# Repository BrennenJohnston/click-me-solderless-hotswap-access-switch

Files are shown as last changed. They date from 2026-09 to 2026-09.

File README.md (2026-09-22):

<!--- Repository structure follows the Open Assistive Technology (OpenAT) Template by Makers Making Change --->

# Click Me: Solderless Hot-Swap Access Switch

A 3D-printed accessibility switch you build without soldering, where the button
itself is an ordinary mechanical keyboard switch you can swap in seconds to change
how hard it is to press.

- **Ordering guide**: `Documentation/ORDERING.md`
- **Assembly guide**: `Documentation/ASSEMBLY.md`
- **Bill of materials**: `Documentation/BOM.csv`
- **Assembly animation**: [youtu.be/RXbbdtwFPiI](https://youtu.be/RXbbdtwFPiI)
- **Status**: work in progress. Built and used, still being iterated

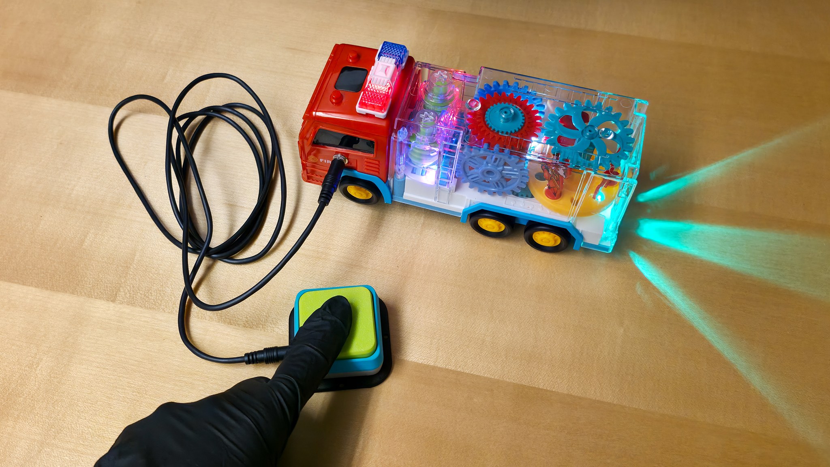
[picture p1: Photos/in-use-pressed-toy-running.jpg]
A black-gloved finger presses the large lime-green button of a Click Me switch, and the toy it is plugged into responds. A black cable runs from the switch to a toy fire truck with a red cab and a clear body full of red, blue and teal gears; the truck's lights are lit and teal beams shine from its 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


## Why this exists

Because I work in the assistive technology field, I end up needing a lot of access
switches, and the ones you can buy cost far more than they should for what is
really a button and a 3.5 mm jack. The part that bothers me more is that they
arrive with one actuation force baked in, so when a switch is too heavy or too
light for the person in front of me, there is not much I can do about it except
order a different switch and wait.

So this is my attempt at a switch where the button is a cheap mechanical keyboard
switch that pulls out and pushes back in by hand. If the force is wrong, you change
it in seconds for the price of a coffee, and hopefully the switch ends up fitting
the person instead of the other way round.

## What it does

- **Plugs into anything with a 3.5 mm switch jack**: switch-adapted toys,
  communication aids, switch interfaces
- **Needs no soldering**: the board arrives from JLCPCB with both parts fitted
- **Needs no screws or glue**: the printed housing snaps together
- **Lets you tune the press**: any Cherry MX compatible keyboard switch fits, in
  whatever force, feel, and sound suits the person
- **Comes with five keycaps**: different sizes and heights, one with a tactile
  pattern you can find by touch

Three of the five keycaps, each on a finished Click Me: flat and textured at the
back left, a tall flat-topped mound at the back right, and the one with the
tactile pattern in front.

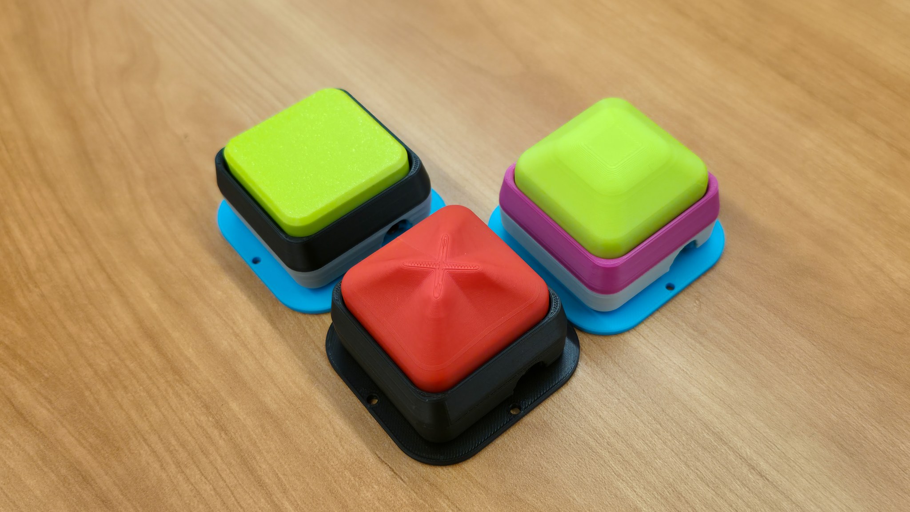
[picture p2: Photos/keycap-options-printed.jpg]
Three finished Click Me switches on a wood table, each with a different keycap. Back left: a flat lime-green keycap with a finely textured top, in a black housing over a grey layer and a light blue base. Back right: a tall lime-green keycap whose sloped sides rise to a raised flat square, in a mage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


## What it costs

About **$8.43 per finished switch** at the moment: $4.82 for the assembled board,
$3.00 for the cable, $0.42 of filament, and $0.19 for the mechanical keyboard
switch. That is with everything bought in small volumes, which is the worst case.
A bigger batch of boards alone took the board cost from $4.82 down to $2.36.
Full breakdown from my own orders is in
[ORDERING.md](Documentation/ORDERING.md#8-what-it-costs).

The Click Me is open assistive technology (OpenAT). Under the terms of the
open-source licenses in this repository, the device may be built, used, and
improved upon by anyone.

## How to obtain the device

### 1. Do it yourself

Order the circuit board following [ORDERING.md](Documentation/ORDERING.md), print
the parts, and build it following [ASSEMBLY.md](Documentation/ASSEMBLY.md). You
need a 3D printer, or access to one.

### 2. Build it for someone else

The board has a minimum order quantity, so building one leaves you with spares.
Most of the board cost is charged once per order rather than per board, so a
bigger batch is much cheaper per unit; 50 boards cost me slightly less in total
than 25 did. That makes this a practical device for a lending library, a school,
or a program to build in quantity, as long as you prove a revision on a small
batch first. See
[ORDERING.md](Documentation/ORDERING.md#how-many-to-order).

## Build instructions

1. **Read [ORDERING.md](Documentation/ORDERING.md)** and order the circuit board
   from JLCPCB with assembly turned on. This is the long-lead item, so order it
   first and print while you wait.
2. **Buy a mechanical keyboard switch** and a 3.5 mm mono cable. Which keyboard
   switch to choose is covered in
   [ASSEMBLY.md section 3](Documentation/ASSEMBLY.md#3-choosing-your-mechanical-keyboard-switch).
3. **Print the four housing parts and one keycap** from
   [`Build_Files/3D_Printing_Files/STL/`](Build_Files/3D_Printing_Files/STL).
4. **Assemble it** following [ASSEMBLY.md](Documentation/ASSEMBLY.md). No
   soldering, no screws, no glue.

## Files

### Documentation

| Document | Link |
|---|---|
| Ordering guide | [ORDERING.md](Documentation/ORDERING.md) |
| Assembly guide | [ASSEMBLY.md](Documentation/ASSEMBLY.md) |
| Bill of materials | [BOM.csv](Documentation/BOM.csv) |
| Changelog | [CHANGES.txt](CHANGES.txt) |

### Build files

| What | Link |
|---|---|
| Gerber files, and the upload-ready ZIP | [`Build_Files/PCB_Build_Files/`](Build_Files/PCB_Build_Files) |
| JLCPCB parts list and placement files | [`BOM_ClickMe.csv`](Build_Files/PCB_Build_Files/BOM_ClickMe.csv), [`CPL_ClickMe.csv`](Build_Files/PCB_Build_Files/CPL_ClickMe.csv) |
| 3D printing files | [`Build_Files/3D_Printing_Files/STL/`](Build_Files/3D_Printing_Files/STL) |

### Design files

| What | Link |
|---|---|
| Circuit design exports and schematic | [`Design_Files/PCB_Design_Files/`](Design_Files/PCB_Design_Files) |

The circuit is exported from EasyEDA Pro in several interchange formats (Altium,
PADS, DISA) plus a schematic PDF and a netlist, so it can be opened in most
circuit design tools.

**CAD source files for the printed parts are not in this repository yet.** They
exist (the parts were designed in Fusion 360) and will be published once they
have been cleaned up. Until then the STL meshes are what is available, so the
printed parts can be reproduced but not easily modified.

### Photos

Assembly photographs, board close-ups and renderings are in
[`Photos/`](Photos). Every one of them is described in words in
[ASSEMBLY.md](Documentation/ASSEMBLY.md), so no step depends on being able to see
an image.

## The circuit

A momentary single-pole switch, and nothing else:

| Reference | Part | LCSC | Fitted by |
|---|---|---|---|
| CN1 | PJ-320B 3.5 mm mono jack | C22355831 | JLCPCB |
| U1 | CPG151101S11-16 hot-swap socket | C41430893 | JLCPCB |
| U2 | Mechanical keyboard switch | none | You, by hand |

The jack's tip and sleeve connect through the keyboard switch. The ring is
deliberately left unconnected, which is the standard assistive-technology switch
pinout: a mono plug works, and a stereo plug still makes contact on tip and
sleeve.

The board is 46 x 46 mm (1.81 x 1.81 in) with rounded corners, two layers, 1.6 mm FR-4.

`U2` appears in the circuit design so the switch footprint positions the housing
cutout correctly, but it is **not** in the files uploaded to JLCPCB, because the maker
supplies that part. See [ORDERING.md](Documentation/ORDERING.md) section 5.

## How to improve this device

This is an open prototype and improvements are welcome. Directions worth exploring:
a latching or toggle variant, a version with two switches on one base, mounting
points for a clamp or mounting arm, a keycap with a replaceable tactile symbol, and
CAD sources so the housing can be resized.

If you build one, the most useful feedback is which keyboard switch you chose and
how the actuation force suited the person using it.

## License

Copyright (c) 2026 Brennen Johnston.

This repository describes Open Hardware:

- Everything needed or used to design, make, test, or prepare the Click Me is
  licensed under the [CERN 2.0 Weakly Reciprocal license (CERN-OHL-W v2) or
  later](https://cern.ch/cern-ohl).
- All software is under the [GNU General Public License v3.0 or later
  (GPL-3.0-or-later)](https://www.gnu.org/licenses/gpl.html).
- Accompanying material such as instruction guides and photographs, which are
  useful but not necessary to design, make, test, or prepare the Click Me, is
  published under a [Creative Commons Attribution-ShareAlike 4.0 license
  (CC BY-SA 4.0)](https://creativecommons.org/licenses/by-sa/4.0/).

You may redistribute and modify this documentation and make products using it
under the terms of the [CERN-OHL-W v2](https://cern.ch/cern-ohl).
This documentation is distributed WITHOUT ANY EXPRESS OR IMPLIED WARRANTY,
INCLUDING OF MERCHANTABILITY, SATISFACTORY QUALITY AND FITNESS FOR A PARTICULAR
PURPOSE. Please see the CERN-OHL-W v2 for applicable conditions.

License texts are in [`LICENSES/`](LICENSES).

Source Location: https://github.com/BrennenJohnston/click-me-solderless-hotswap-access-switch

## Attribution

The device was designed by Brennen Johnston.

The documentation and repository structure follow the OpenAT Template created by
Makers Making Change / Neil Squire Society, used under a CC BY-SA 4.0 license:
[github.com/makersmakingchange/OpenAT-Template](https://github.com/makersmakingchange/OpenAT-Template).

### Contributors

Designers:
- Brennen Johnston

Testers:
- Brennen Johnston

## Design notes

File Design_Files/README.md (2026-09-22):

# Design files

This folder contains the design files for the device.

`PCB_Design_Files/` holds the circuit exported from EasyEDA Pro in several
interchange formats so it can be opened in most circuit design tools:

- `Altium_*.zip`, `PADS_*.zip`, `DISA_*.zip`: schematic and board in Altium,
  PADS and DISA formats.
- `PDF_*.zip`: the schematic as a PDF, for reading without any EDA tool.
- `Netlist_Schematic1_*.tel`: the netlist: three parts and two nets.
- `BOM_Board1_*.xlsx`, `PickAndPlace_*.xlsx`: the unmodified EasyEDA exports.
  The upload-ready versions in `Build_Files/PCB_Build_Files/` differ: they omit
  `U2`, the mechanical keyboard switch, which the maker supplies.

CAD source files for the printed parts are not published yet. They exist in
Fusion 360 and will be added once cleaned up.

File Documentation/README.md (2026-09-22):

# Documentation

This folder contains the documentation for the device, written in Markdown so it
reads in a browser, in a terminal, or through a screen reader without any
conversion step.

- `ORDERING.md`: ordering the assembled circuit board from JLCPCB.
- `ASSEMBLY.md`: printing the parts, choosing a keyboard switch and a keycap,
  building the device, and testing it.
- `BOM.csv`: the full bill of materials, including what you print and what you buy.

Every photograph referenced by these documents is described in the surrounding
text, so no instruction depends on being able to see an image.

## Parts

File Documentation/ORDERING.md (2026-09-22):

# Ordering the Click Me circuit board

This guide orders the Click Me printed circuit board (PCB) from JLCPCB, with the
two electronic parts already soldered on. You do not solder anything.

The board is small and simple: a 3.5 mm mono jack and a socket that a mechanical
keyboard switch clicks into. Everything else about the device is 3D printed.

Read [ASSEMBLY.md](ASSEMBLY.md) for what to do once the boards arrive.

> **Status: work in progress.** These are the settings used for the boards in the
> photos, ordered in July 2026. JLCPCB changes its website, its option names and
> its prices. Treat every screen name below as "look for something like this"
> rather than an exact match, and check the preview before you pay.

## 1. What you need before you start

Three files from this repository, all in
[`Build_Files/PCB_Build_Files/`](../Build_Files/PCB_Build_Files):

| File | What it is |
|---|---|
| `Gerber_PCB1_2026-09-21.zip` | The board itself: copper, holes, outline |
| `BOM_ClickMe.csv` | The parts list: which components to solder |
| `CPL_ClickMe.csv` | Where each component sits and which way round |

Download all three. Do not unzip the Gerber file; JLCPCB wants the `.zip`.

You also need a JLCPCB account, and a payment method.

## 2. Upload the board file

1. Go to [jlcpcb.com](https://jlcpcb.com).
2. Select **Add gerber file** and choose `Gerber_PCB1_2026-09-21.zip`.
3. Wait for the preview to appear.
4. **Check the preview before going further.** You should see a small square board
   with two rounded mounting slots and one square outline near the middle. The
   dimensions should read about **46 x 46 mm (1.81 x 1.81 in)**. If the size is
   wildly different, or the preview is blank, the upload failed. Try again rather
   than continuing.

## 3. Board options

These are the options used for the boards in the photos. Where a name has changed,
pick the nearest equivalent.

| Option | Value | Why |
|---|---|---|
| Layers | 2 | What the design uses |
| Dimensions | filled in automatically | From the board file |
| PCB thickness | 1.6 mm | Standard; the printed housing is sized for it |
| PCB material | FR-4 | Standard fibreglass board |
| Outer copper weight | 1 oz | Standard |
| Surface finish | Lead-free HASL | Standard, and no lead |
| Solder mask | Purple | Cosmetic only; pick any colour you like |
| Silkscreen | White | Cosmetic only |
| Via covering | Tented | Standard |
| Minimum hole size | 0.3 mm | Standard, no extra charge |
| Remove order number | leave at the default | Cosmetic only |

Everything not listed can stay at its default.

**Quantity.** The form has a minimum, normally 5 boards. Building one Click Me
needs one board, so you will have spares whatever you choose. A bigger batch is
dramatically cheaper per board, because so much of the cost is charged once per
order. Even so, read section 8 before you size your order, because cheaper per board
is not the same as the right number to buy.

## 4. Turn on assembly

This is the step that makes the board solderless for you.

1. Switch **PCB Assembly** on.
2. Set the assembly side to the **top side** only.
3. Set how many of your boards to have assembled. This can be fewer than the
   number of bare boards, and assembled boards cost more than bare ones.
4. Continue to the parts upload step.

**Economic or Standard?** JLCPCB offers tiers under different names. Economic is
cheaper and covers ordinary surface-mount parts, which is all this board has.
Standard costs more and handles a wider range of parts. The batch in the photos
was made as Standard. With only two surface-mount parts on one side, Economic may
well be offered and accepted. Pick whichever the form allows for your upload, and
if only one tier is offered, take it.

## 5. Upload the parts list and positions

1. Upload `BOM_ClickMe.csv` where it asks for the **BOM** or parts list.
2. Upload `CPL_ClickMe.csv` where it asks for the **CPL**, **pick and place**, or
   **component placement** file.
3. Continue to the parts confirmation screen.

**You should see exactly two parts:**

| Designator | Part | LCSC part number | What it is |
|---|---|---|---|
| CN1 | PJ-320B | C22355831 | The 3.5 mm mono jack your cable plugs into |
| U1 | CPG151101S11-16 | C41430893 | The socket the keyboard switch clicks into |

If a **third** part appears, or a part number differs from the table, stop and
check you uploaded the files from this repository. The mechanical keyboard switch
is deliberately not in these files. You buy that separately, and paying JLCPCB to
fit one would defeat the point of a hot-swap socket.

If either part shows as out of stock, JLCPCB will offer a substitute. A different
3.5 mm mono jack in the same PJ-320B footprint is usually fine. For the socket,
any Kailh-compatible MX hot-swap socket in the same footprint is usually fine.
Read the substitute's dimensions before accepting it.

## 6. Review and order

1. Work through the remaining screens: shipping, customs, and payment.
2. Before paying, check the summary shows the board quantity, the assembled
   quantity, and two parts.
3. Place the order.

Boards typically take a few weeks including shipping. JLCPCB will send your order
through an engineering review and may email a question; answering it promptly
avoids a delay.

## 7. What arrives, and what you still need

**In the parcel:** your bare boards, and your assembled boards with the jack and
the socket already soldered on.

**You also need, per Click Me:**

| Item | Notes |
|---|---|
| One mechanical keyboard switch | Cherry MX compatible, 5-pin or 3-pin. This is the part that sets how hard the button is to press (see "Choosing your keyboard switch" in [ASSEMBLY.md](ASSEMBLY.md)) |
| A 3.5 mm mono cable | To connect the Click Me to the device it operates |
| Filament | For the four housing parts and one keycap |

No screws and no glue: the housing is snap-fit.

## 8. What it costs

These are the real figures from my own orders, in US dollars. **Treat them as a
ceiling, not a target**, for the reason given at the end of this section.

### The board order

25 assembled boards, ordered July 2026, shipped to the United States.

PCB manufacturing:

| Line | Cost |
|---|---|
| Engineering fee | $4.00 |
| Surface finish | $1.60 |
| Board | $11.80 |
| **Subtotal** | **$17.40** |

Assembly:

| Line | Cost |
|---|---|
| Setup fee | $25.56 |
| Stencil | $8.25 |
| Components | $2.08 |
| Extended components fee | $3.06 |
| SMT assembly | $0.20 |
| Packaging fee | $0.49 |
| **Subtotal** | **$39.64** |

What I actually paid:

| Line | Cost |
|---|---|
| Merchandise total | $57.00 |
| Shipping | $43.49 |
| Customs duties and taxes | $19.95 |
| Coupon discount | -$10.00 |
| PayPal fee | $0.55 |
| Sales tax | $9.60 |
| **Order total** | **$120.59** |
| **Per assembled board** | **$4.82** |

Two of those lines are mine rather than yours. The $10.00 was a coupon I happened
to have, and the PayPal fee depends on how you pay. Without the coupon the same
order is $130.59, or **$5.22 per board**, which is the safer number to budget
against.

### Everything else, per Click Me

| Item | Bought as | Per unit |
|---|---|---|
| Mechanical keyboard switch | $13.99 for 72 | $0.19 |
| PLA filament, 34.03 g | $12.47 per 1 kg roll | $0.42 |
| 3.5 mm mono cable | single | $3.00 |

Sources for the two Amazon items are in
[BOM.csv](BOM.csv).

### Cost of one finished Click Me

| Part | Cost |
|---|---|
| Assembled board | $4.82 |
| Mechanical keyboard switch | $0.19 |
| Printed housing and keycap | $0.42 |
| 3.5 mm mono cable | $3.00 |
| **Total** | **$8.43** |

Without the coupon, $8.83.

### How many to order

Most of what you pay is charged once per order rather than per board. The
engineering fee, the assembly setup fee and the stencil come to $37.81 before a
single board is made, and shipping, customs and tax added another $73.59, which is
61 percent of the total. Only about $16 of that $57 merchandise total actually
scaled with how many boards I asked for.

My own two orders show what that does to the per-board price:

| Order | Boards | Order total | Per board |
|---|---|---|---|
| Earlier revision | 50 | $118.10 | $2.36 |
| Current revision, in the photographs | 25 | $120.59 | $4.82 |

Twice as many boards for slightly less money. The arithmetic says order as many
as you will ever want in one go.

**Do not let it talk you into a big batch of an unproven board.** The 25-board
order is the smaller of the two on purpose. I had corrected something in the
design after the 50-board run, and I wanted boards in my hand to test before
committing to another large order. That is the right instinct, and the cost
structure makes it cheap advice to follow: because the per-order fees dominate,
a small proving batch costs almost the same as a large one, so you lose very
little by ordering 25 first and a great deal by ordering 100 of something with a
mistake in it.

So: order a small batch of any revision you have not held yet, confirm a
keyboard switch seats and the housing closes around it, and only then order the
quantity your lending library, school or caseload actually needs.

### These prices are higher than they need to be

Everything above was bought in small volumes, which is the worst case for price.
Every line in the bill of materials has room to come down with a bulk order.
The cable is the obvious target: at $3.00 it is the second most expensive part of
the whole device, and it is an ordinary audio cable. I will look at bulk pricing properly
once the design is finalised. Until then, budget from these numbers and expect to
beat them.

## 9. If something goes wrong

| What you see | What it usually means | What to do |
|---|---|---|
| Preview is blank or the wrong shape | The `.zip` was unzipped, or the wrong file was uploaded | Upload `Gerber_PCB1_2026-09-21.zip` exactly as downloaded |
| Board size is not about 46 x 46 mm | Wrong file, or units misread | Re-download and re-upload |
| A third part appears in the parts list | The files came from somewhere other than this repository | Re-download `BOM_ClickMe.csv` and `CPL_ClickMe.csv` |
| A part is out of stock | Normal | Accept a substitute in the same footprint, after reading its dimensions |
| JLCPCB emails an engineering question | Normal for a first order | Answer it; the order is paused until you do |

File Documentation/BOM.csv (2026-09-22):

Section | Item | Quantity | Reference | Supplier / Part number | Bought as | Cost per unit (USD) | Notes
Assembled by JLCPCB | PJ-320B 3.5 mm mono jack | 1 | CN1 | LCSC C22355831 | Included in the board order |  | Soldered by JLCPCB. Tip and sleeve wired; ring deliberately unconnected
Assembled by JLCPCB | CPG151101S11-16 hot-swap socket | 1 | U1 | LCSC C41430893 | Included in the board order |  | Soldered by JLCPCB. Accepts any Cherry MX compatible keyboard switch
Assembled by JLCPCB | Assembled printed circuit board | 1 |  | JLCPCB (see Documentation/ORDERING.md) | 25 boards for $120.59 delivered | 4.82 | 46 x 46 mm 2-layer FR-4 1.6 mm. Per-unit cost falls sharply with batch size
You supply | Mechanical keyboard switch | 1 | U2 position | Any Cherry MX compatible switch. I used https://www.amazon.com/dp/B0GC33V4HK | $13.99 for 72 | 0.19 | Not fitted by JLCPCB. Sets the actuation force (see ASSEMBLY.md section 3)
You supply | 3.5 mm mono cable | 1 |  | Any male-to-male 3.5 mm cable. I used https://www.amazon.com/dp/B0DCYYJDBL | Single unit | 3.00 | Connects the Click Me to the device it operates
You print | Base | 1 | Part_0 | Build_Files/3D_Printing_Files/STL |  |  | 60.0 x 60.0 x 7.4 mm
You print | Carrier | 1 | Part_1 | Build_Files/3D_Printing_Files/STL |  |  | 46.3 x 46.3 x 14.0 mm
You print | Retainer | 1 | Part_2 | Build_Files/3D_Printing_Files/STL |  |  | 50.0 x 50.0 x 9.5 mm
You print | Housing | 1 | Part_3 | Build_Files/3D_Printing_Files/STL |  |  | 50.0 x 50.0 x 11.0 mm
You print | Keycap | 1 | One of Part_4.0 to Part_4.4 | Build_Files/3D_Printing_Files/STL |  |  | 42.4 x 42.4 mm. Five alternatives; print one. See ASSEMBLY.md section 4
You print | PLA filament for all five printed parts | 34.03 g |  | Bambu Lab PLA Basic or equivalent | $12.47 per 1 kg roll | 0.42 | Total filament for one complete housing and one keycap
Not required | Screws | 0 |  |  |  |  | The housing is snap-fit. No screws no inserts no glue
TOTAL | One finished Click Me | 1 |  |  |  | 8.43 | Small-volume pricing (see ORDERING.md section 8). Bulk buying should reduce this

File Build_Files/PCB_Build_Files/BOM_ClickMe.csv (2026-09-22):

Comment | Designator | Footprint | LCSC Part #
PJ-320B | CN1 | AUDIO-SMD_PJ-320B | C22355831
CPG151101S11-16 | U1 | SMD_KEYBOARD-SW | C41430893

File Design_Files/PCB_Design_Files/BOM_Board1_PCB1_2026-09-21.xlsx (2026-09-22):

No. | Quantity | Comment | Designator | Footprint | Value | Manufacturer Part | Manufacturer | Supplier Part | Supplier
1 | 1 | PJ-320B | CN1 | AUDIO-SMD_PJ-320B |  | PJ-320B | SOFNG(硕方) | C22355831 | LCSC
2 | 1 | CPG151101S11-16 | U1 | SMD_KEYBOARD-SW |  | CPG151101S11-16 | HanElectricity(瀚源) | C41430893 | LCSC
3 | 1 | CPG151101D13 | U2 | KEY-TH_CPG151101D21X |  | CPG151101D13 | HanElectricity(瀚源) | C49234235 | LCSC

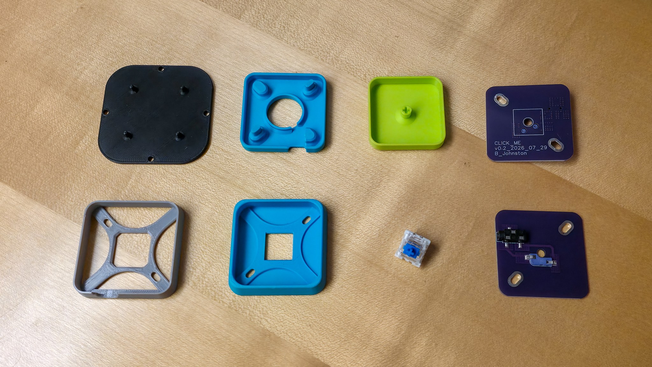
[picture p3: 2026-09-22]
Photos/assembly-00-all-parts.jpg

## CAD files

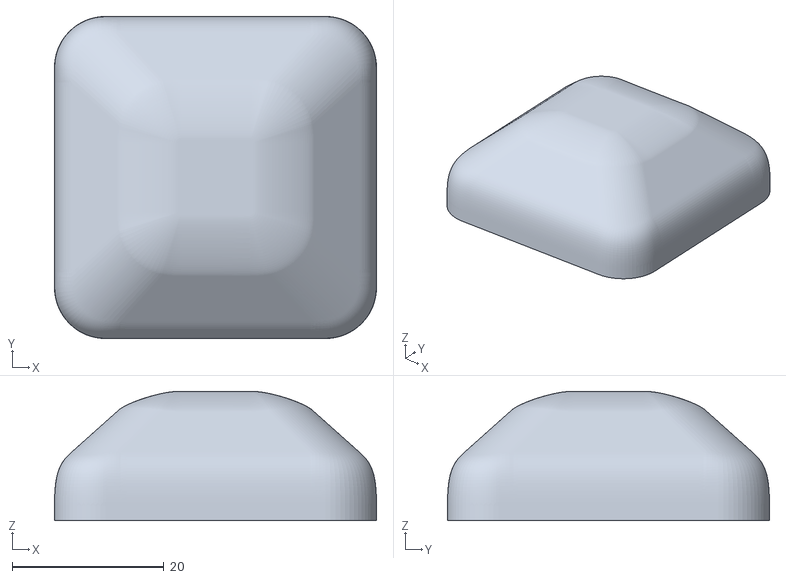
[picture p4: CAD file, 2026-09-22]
Build_Files/3D_Printing_Files/STL/Part_4.3_B_Switch_v0.5.stl
42.4 x 42.4 x 17.0

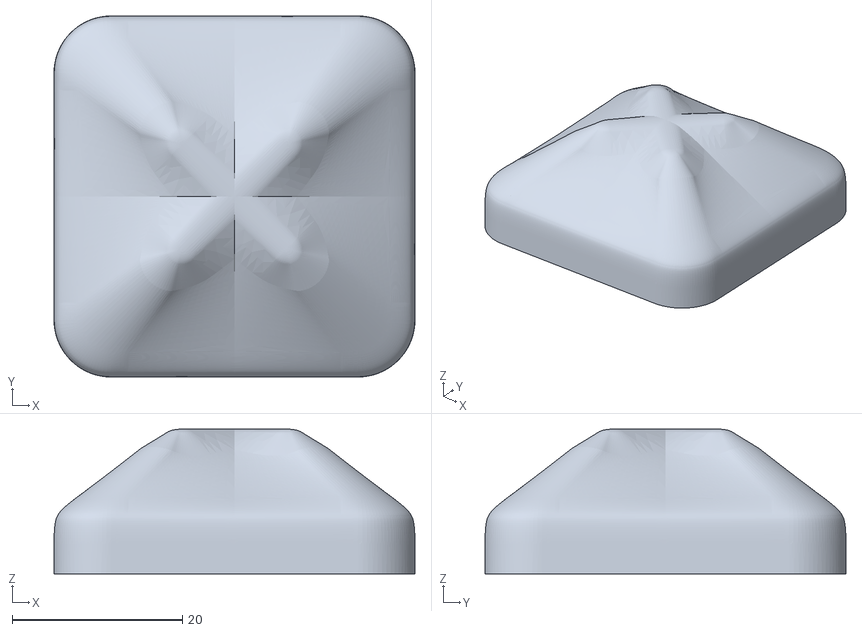
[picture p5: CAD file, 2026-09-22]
Build_Files/3D_Printing_Files/STL/Part_4.4_B_Switch_v0.5.stl
42.4 x 42.4 x 17.0

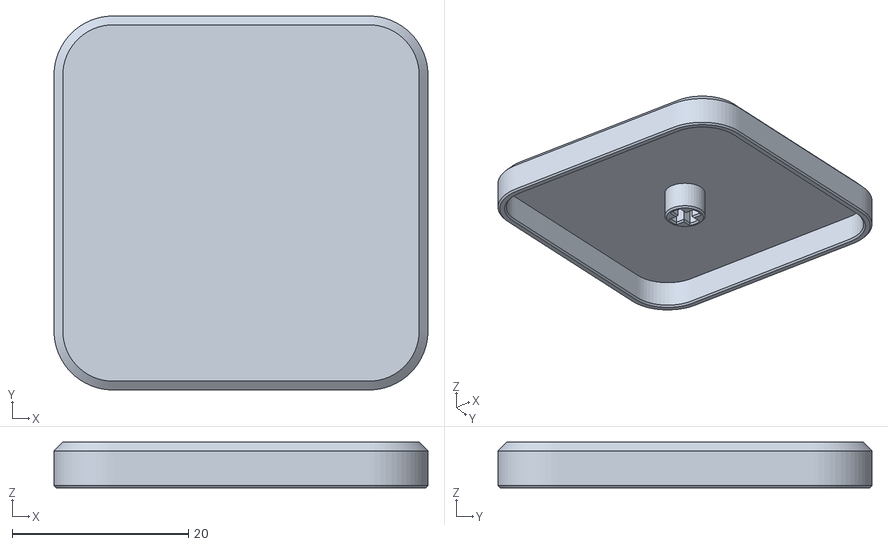
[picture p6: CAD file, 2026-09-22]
Build_Files/3D_Printing_Files/STL/Part_4.2_B_Switch_v0.5.stl
42.4 x 42.4 x 5.20

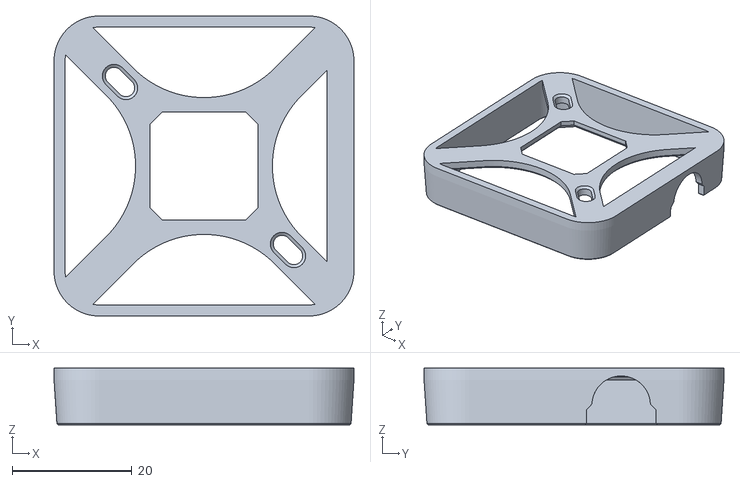
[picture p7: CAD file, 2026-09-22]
Build_Files/3D_Printing_Files/STL/Part_2_B_Switch_v0.5.stl
50.0 x 50.0 x 9.50

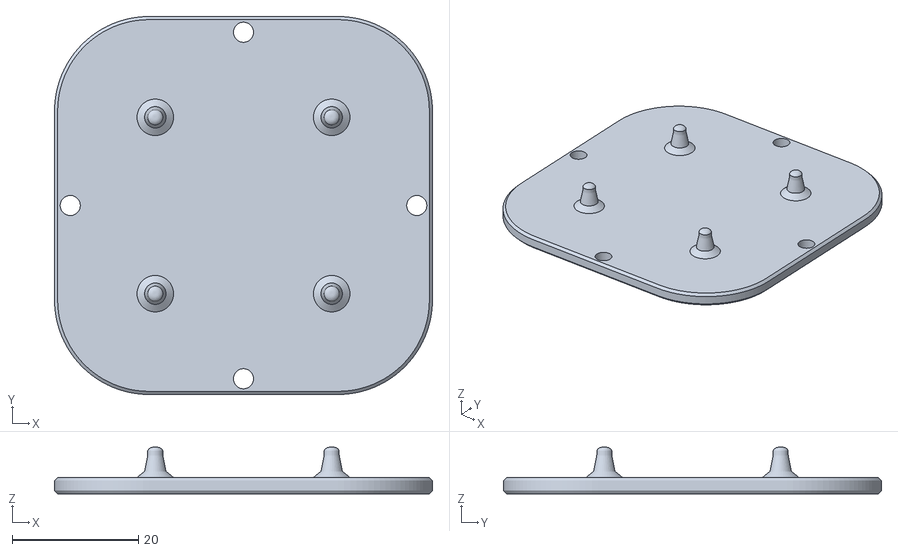
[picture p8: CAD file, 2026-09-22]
Build_Files/3D_Printing_Files/STL/Part_0_B_Switch_v0.5.stl
60.0 x 60.0 x 7.40

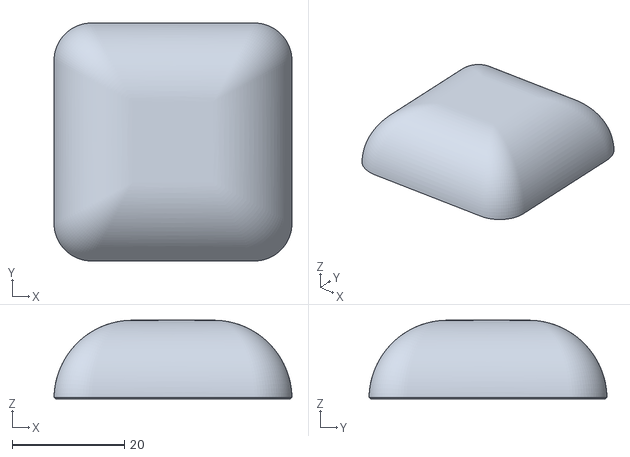
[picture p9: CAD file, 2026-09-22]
Build_Files/3D_Printing_Files/STL/Part_4.1_B_Switch_v0.5.stl
42.4 x 42.4 x 14.0

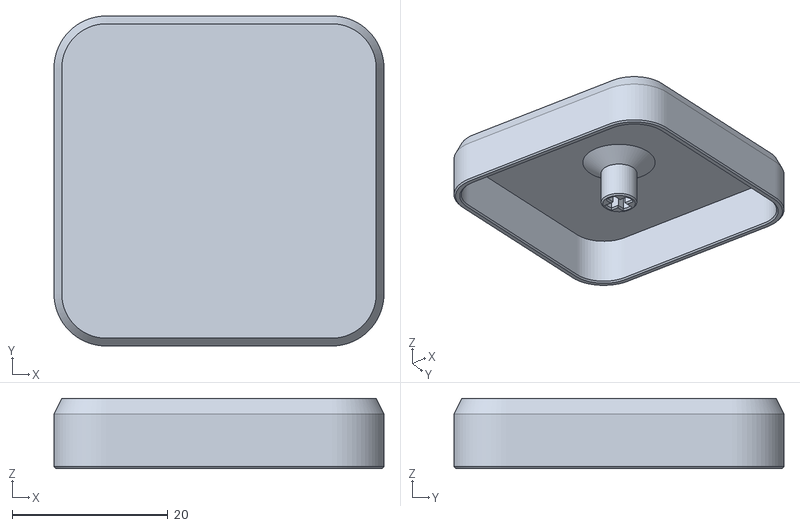
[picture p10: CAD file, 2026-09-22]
Build_Files/3D_Printing_Files/STL/Part_4.0_B_Switch_v0.5.stl
42.4 x 42.4 x 9.00

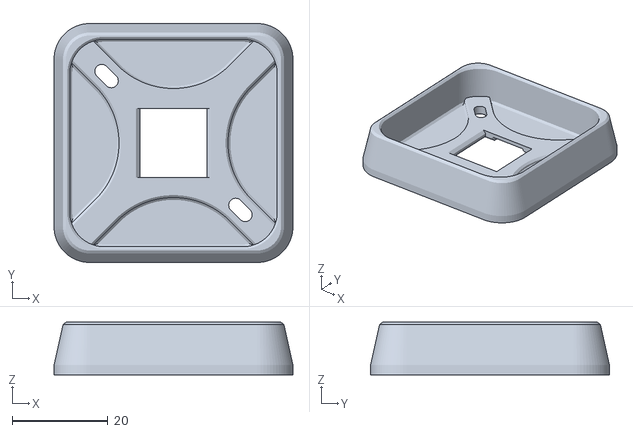
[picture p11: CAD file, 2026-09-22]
Build_Files/3D_Printing_Files/STL/Part_3_B_Switch_v0.5.stl
50.0 x 50.0 x 11.0

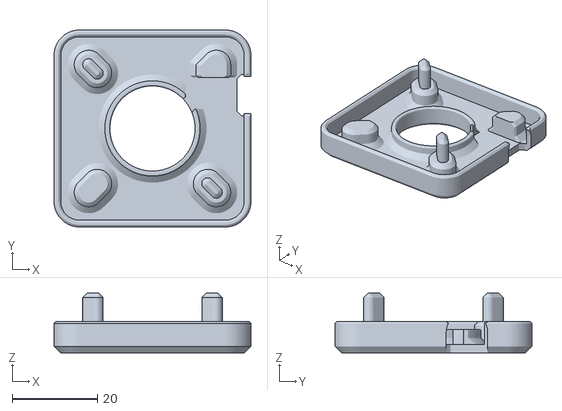
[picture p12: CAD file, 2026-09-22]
Build_Files/3D_Printing_Files/STL/Part_1_B_Switch_v0.5.stl
46.3 x 46.3 x 14.0

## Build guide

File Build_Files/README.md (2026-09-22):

# Build files

This folder contains the build files for the device.

- `PCB_Build_Files/`: everything uploaded to the board manufacturer: the Gerber
  ZIP, the parts list (`BOM_ClickMe.csv`) and the component placement file
  (`CPL_ClickMe.csv`). See `Documentation/ORDERING.md`.
- `3D_Printing_Files/STL/`: the four housing parts and the five keycap options.
  Print `Part_0` to `Part_3` and exactly one `Part_4.x`. See
  `Documentation/ASSEMBLY.md`.

The STL files are saved in assembly position rather than laid out for printing,
so load them into a slicer one at a time or drop each one onto the build plate.

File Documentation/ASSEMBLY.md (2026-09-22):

# Building the Click Me

This guide turns a set of 3D-printed parts, one assembled circuit board and one
mechanical keyboard switch into a finished Click Me access switch.

**No soldering, no screws and no glue.** The board arrives with its two parts
already fitted, and the printed housing snaps together.

For how to obtain the board, see [ORDERING.md](ORDERING.md).

> **Status: work in progress.** The print settings in section 2 are a starting
> point, not a tested profile. If you print a set, what worked and what did not is
> useful feedback.

## 1. What the device is made of

| Item | Where it comes from |
|---|---|
| Four printed housing parts | You print them: `Part_0` to `Part_3` |
| One printed keycap | You print one of `Part_4.0` to `Part_4.4` |
| One assembled circuit board | JLCPCB (see [ORDERING.md](ORDERING.md)) |
| One mechanical keyboard switch | You buy it (see section 3) |
| One 3.5 mm mono cable | You buy it |

Finished, the Click Me is about **60 x 60 mm (2.4 x 2.4 in)** across the base and
between about **29 mm and 38 mm (1.1 to 1.5 in)** tall depending on which keycap
you choose.

### The parts, and what each one does

Every part laid out before assembly. Top row, left to right: the black base, the
blue carrier, a green keycap, and the circuit board seen from its silkscreen face.
Bottom row, left to right: the grey retainer, the blue housing, a blue mechanical
keyboard switch, and a second board seen from its component face.

![The parts laid out on a wood table in two rows. Top row, left to right: the black base plate, the light blue carrier with a round opening and four posts, a lime-green keycap resting stem upward, and the circuit board showing its silkscreen face. Bottom row: the grey X-braced retainer, the blue housing with a square window, a small blue and clear mechanical keyboard switch, and a second circuit board showing its component face with the black jack and the socket.](../Photos/assembly-00-all-parts.jpg)

| Part | Size | What it does |
|---|---|---|
| `Part_0` | 60.0 x 60.0 x 7.4 mm | Base. The bottom of the device, with a notch in one edge for the cable |
| `Part_1` | 46.3 x 46.3 x 14.0 mm | Carrier. Sits in the base and holds the board, with a round opening that clears the jack |
| `Part_2` | 50.0 x 50.0 x 9.5 mm | Retainer. An X-braced frame that presses the board down |
| `Part_3` | 50.0 x 50.0 x 11.0 mm | Housing. The outer wall, with a square window the keyboard switch pokes through |
| `Part_4.x` | 42.4 x 42.4 mm | Keycap. The surface the person actually presses. Pick one (see section 4) |

### Which side of the board is which

This matters, and it is easy to get backwards.

- The **component face** carries the black 3.5 mm jack and the small socket. This
  is the side JLCPCB soldered.
- The **switch face** carries the white text `CLICK_ME`, a square outline, and two
  small holes inside that square.

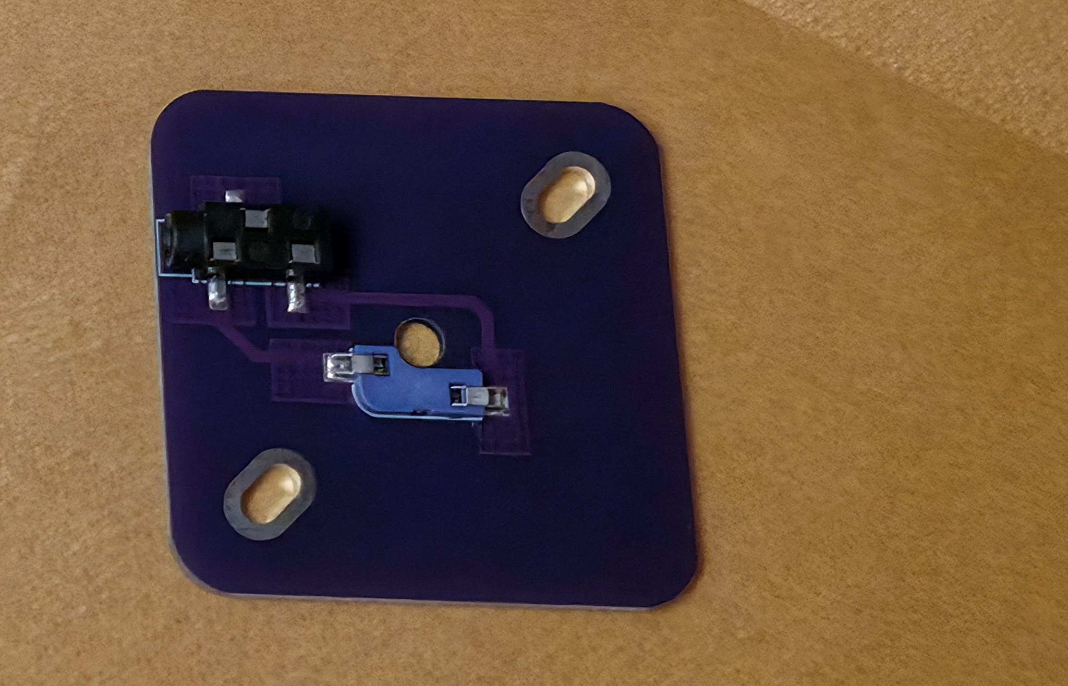
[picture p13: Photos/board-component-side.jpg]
The component face of the circuit board: a black 3.5 mm jack at one edge, a small blue hot-swap socket in the middle, magenta traces linking the two, and a gold-plated oval mounting slot at opposite corners.


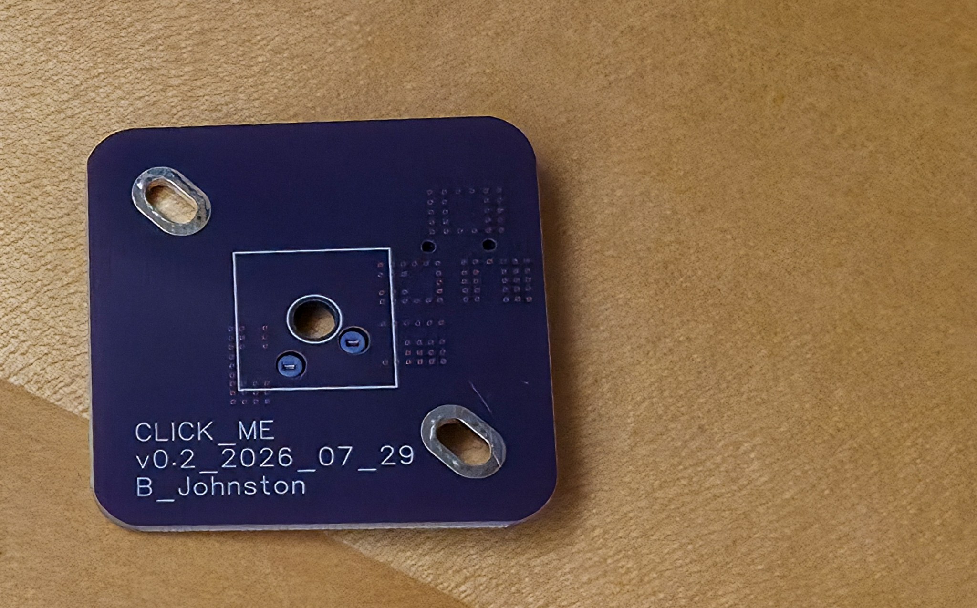
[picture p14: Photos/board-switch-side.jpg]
The switch face of the circuit board: white silkscreen reading CLICK_ME, v0.2_2026_07_29, B_Johnston, a white square outline around one large centre hole and two smaller pin holes, and a gold-plated oval mounting slot at opposite corners.


The mechanical keyboard switch pushes in from the **switch face**. Its two metal
pins pass through those two holes and grip the socket waiting on the other side.
That is what makes the board hot-swap: the switch is held by friction, not solder,
so it can be pulled out and replaced with a different one at any time.

In the finished device the **switch face points up** and the component face points
down into the carrier.

## 2. Print the parts

Print `Part_0`, `Part_1`, `Part_2` and `Part_3`, plus **one** of the `Part_4.x`
keycaps. The five keycaps are alternatives, not five steps; you need one.

The files are in
[`Build_Files/3D_Printing_Files/STL/`](../Build_Files/3D_Printing_Files/STL).

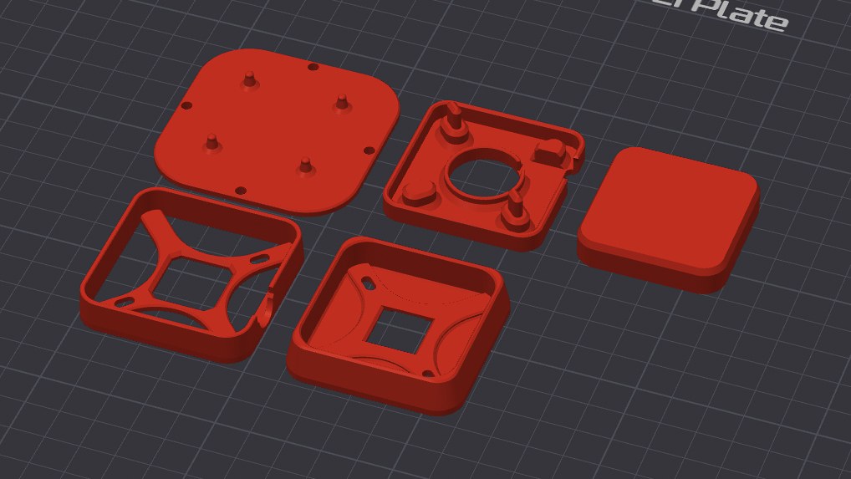
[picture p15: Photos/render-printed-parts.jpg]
A computer rendering of the five printed parts in red: the base plate with four posts, the carrier with a round opening, the X-braced retainer, the housing with a square window, and a flat keycap.


**The parts are saved in assembly position, not laid out for printing.** If you
load them all into a slicer at once they will appear stacked inside one another.
Load them one at a time, or use the slicer command that drops a part onto the
build plate.

### Suggested starting settings

These are a reasonable starting point rather than a verified profile. Print one
part first and check the fit before committing to a full set.

| Setting | Suggestion | Why |
|---|---|---|
| Material | PLA | Easy, rigid enough, and the parts carry no heat or load |
| Layer height | 0.2 mm | Fast, and none of the parts need fine detail |
| Walls | 3 or more | The snap features flex; thin walls crack there first |
| Infill | 20 percent or more | Enough for a part that gets pressed repeatedly |
| Supports | None | Every part prints without them in its saved orientation |

**Keycap tip.** Printing the keycap with its top face down against the build plate
avoids supports inside the stem cavity, and a textured build plate transfers a
fine grip texture onto the pressing surface. The green keycap in the photographs
was printed this way.

**If a part does not fit**, printers differ by a few tenths of a millimetre.
Adjusting the horizontal expansion or X/Y compensation setting by about 0.05 to
0.1 mm usually resolves a snap fit that is too tight or too loose.

## 3. Choosing your mechanical keyboard switch

This is the most important accessibility decision in the whole build, and it costs
very little to change your mind, because the switch pulls straight out.

Any **Cherry MX compatible** mechanical keyboard switch fits. These are sold for
custom keyboards and are widely available. Both 3-pin and 5-pin switches work.

Three things vary, and all three matter:

**How much force it takes to press.** Published figures are usually given in
grams-force (gf). Lighter switches suit someone with limited strength; heavier
switches suit someone who rests a hand on the button and needs it not to trigger
by accident.

**Whether you feel it activate.** A linear switch is smooth all the way down. A
tactile switch has a bump you can feel at the moment it activates.

**Whether you hear it activate.** A clicky switch makes an audible click. For
someone who cannot easily see the device they are operating, that click is
confirmation the press registered.

| Family | Typical published force | Feel | Sound |
|---|---|---|---|
| Light linear | around 35 gf | Smooth | Quiet |
| Standard linear | around 45 gf | Smooth | Quiet |
| Tactile | around 45 to 55 gf | Bump at activation | Quiet |
| Clicky | around 50 to 60 gf | Bump at activation | Audible click |
| Heavy | around 60 to 80 gf | Varies | Varies |

Forces vary between manufacturers even within a family, so check the figure the
seller publishes for the exact switch rather than relying on its colour.

The device in the photographs uses a clicky switch, which I picked because the
audible click tells you the press registered without having to watch the toy.

I am not going to name one switch as the right answer. The right actuation force
is the one that suits the person using the button, and that is not something I can
decide from here. Buy two or three and let them tell you which feels best. They
cost very little and swapping one takes seconds.

## 4. Choosing your keycap

All five keycaps are 42.4 x 42.4 mm (1.67 x 1.67 in) across. They differ in height
and in the shape of the pressing surface.

Four of the five, as computer renderings.

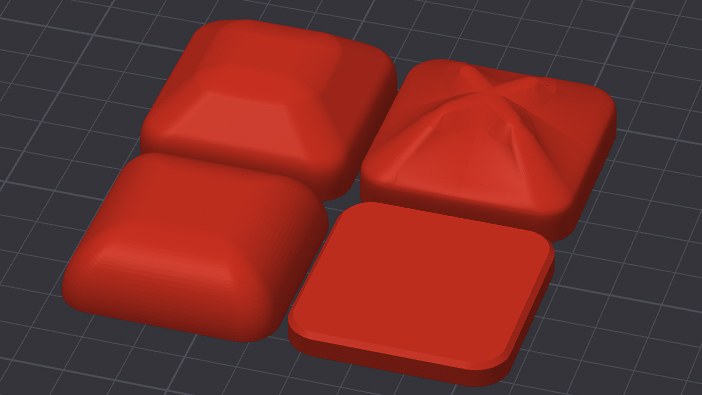
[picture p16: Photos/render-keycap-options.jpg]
A computer rendering of four keycap options in red: a tall chamfered dome, a tall dome with a faceted star pattern radiating from its centre, a lower rounded dome, and a thin flat slab.


Three of them printed, each on a finished Click Me: the flat `Part_4.0` at the
back left, the tall flat-topped `Part_4.3` at the back right, and `Part_4.4`, the
one with the tactile pattern, in front. The housing parts are printed in different
colours too.

![Three finished Click Me switches on a wood table, each with a different keycap. Back left: a flat lime-green keycap with a finely textured top, in a black housing over a grey layer and a light blue base. Back right: a tall lime-green keycap whose sloped sides rise to a raised flat square, in a magenta housing over a grey layer and a light blue base. In front: an all-black Click Me with a tall red keycap shaped like a four-sided pyramid, with a raised, finely ridged X on its peak whose arms point to the corners.](../Photos/keycap-options-printed.jpg)

| File | Height | Shape | Suits |
|---|---|---|---|
| `Part_4.2` | 5.2 mm | Flat, slimmest | The lowest profile, least likely to be knocked |
| `Part_4.0` | 9.0 mm | Flat, low | A flat target with a little more height |
| `Part_4.1` | 14.0 mm | Smooth rounded dome | A hand or fist resting on top |
| `Part_4.3` | 17.0 mm | Tall, flat-topped mound | Reaching the button without leaning in |
| `Part_4.4` | 17.0 mm | Tall, with a faceted star pattern | The same height, with a surface you can identify by touch |

`Part_4.4` is the only one with a tactile pattern on the pressing surface. If the
person using the device relies on touch to find and identify controls, that is the
one to try first.

## 5. Put it together

Six steps. Each one has a photograph showing the result.

The animation below runs the whole sequence, from the parts in an exploded view down
to the finished switch. It plays once when the page loads and then stops on the
assembled device; reload the page to watch it again. A longer version, which you can
pause and scrub through, is on YouTube as
[Click Me: Solderless Hot-Swap Access Switch v0.32](https://youtu.be/RXbbdtwFPiI).

It was rendered from revision v0.32 of the housing, so small details differ from the
v0.5 parts you will print. The order of assembly is the same. The numbered steps
below are the authoritative sequence and do not depend on the animation.

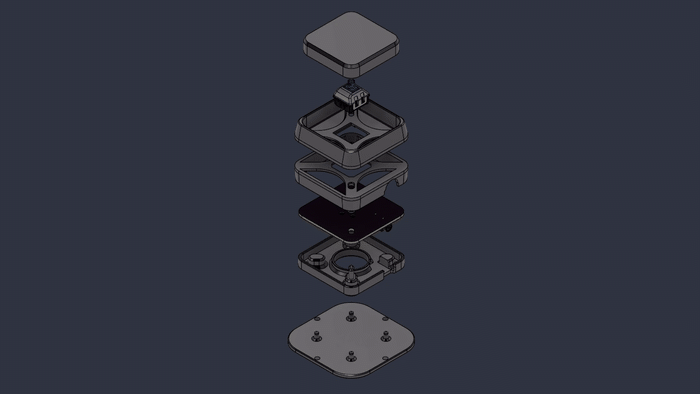
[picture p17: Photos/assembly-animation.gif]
A computer animation of the Click Me assembling itself. Seven parts hang apart in an exploded stack and lower into place one after another: the base plate at the bottom, then the carrier, the circuit board, the X-braced retainer, the housing, the mechanical keyboard switch, and the keycap last. It 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


1. **Fit the carrier into the base.** Press `Part_1` down into `Part_0` so the
   round opening in the carrier lines up with the notch in the edge of the base.
   That notch is where the cable will come out.

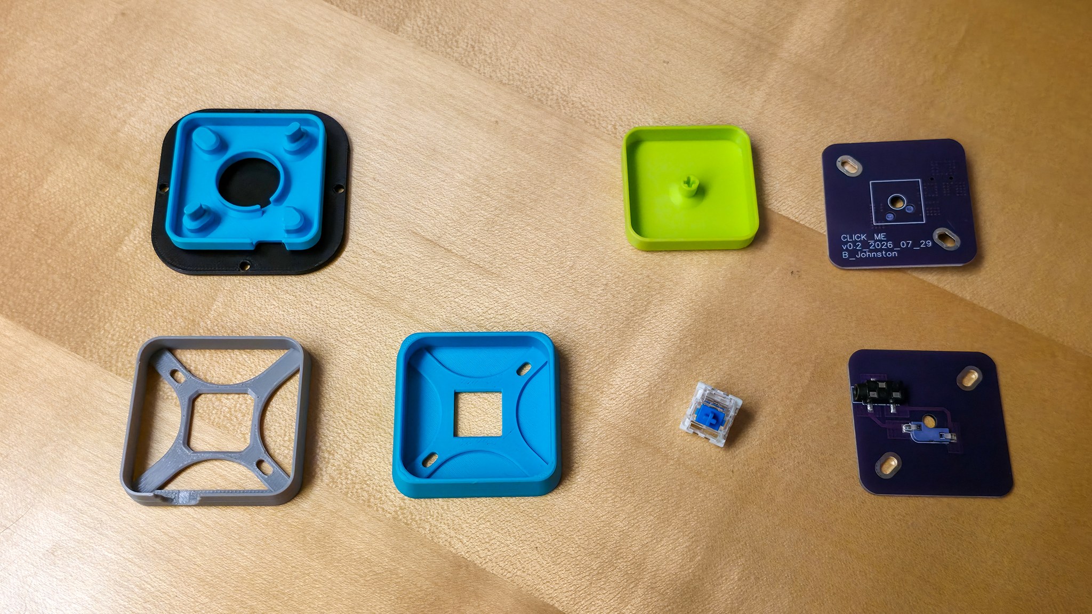
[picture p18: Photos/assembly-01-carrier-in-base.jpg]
The light blue carrier pressed into the black base plate, its round opening facing up. The green keycap, circuit board, grey retainer, blue housing and keyboard switch wait alongside.
   

2. **Drop the board in, component face down.** Lay the circuit board into the
   carrier with the black jack facing down into the round opening, so the white
   `CLICK_ME` text faces up at you. The jack should sit in the opening and point
   towards the notch in the base.

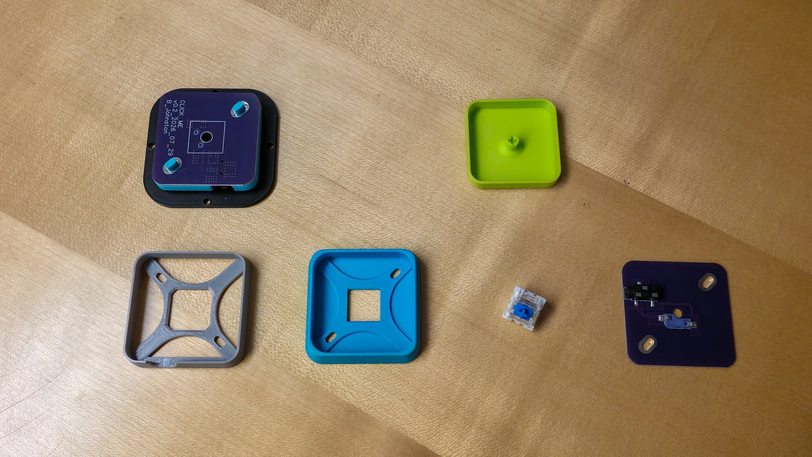
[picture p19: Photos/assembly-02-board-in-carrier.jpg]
The circuit board seated in the carrier with its silkscreen face up, so CLICK_ME and the two gold mounting slots are visible. The retainer, housing, keycap and keyboard switch are still to one side.
   

3. **Lay the retainer over the board.** Place `Part_2`, the X-braced grey frame,
   on top of the board so its arms press the board down against the carrier. The
   square opening in the middle of the frame leaves the switch holes clear.

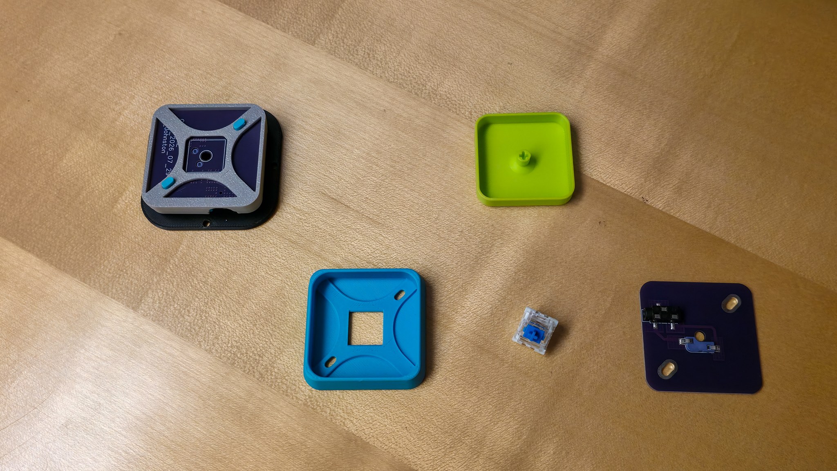
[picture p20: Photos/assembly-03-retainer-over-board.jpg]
The grey X-braced retainer laid over the circuit board, its arms pressing the board down and its square centre opening leaving the switch holes clear.
   

4. **Snap the housing on.** Press `Part_3` down over the stack until it seats. You
   should now see the board through a square window in the middle.

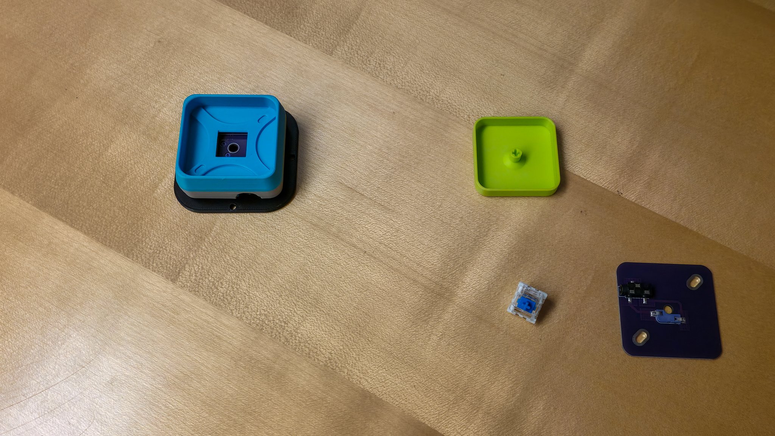
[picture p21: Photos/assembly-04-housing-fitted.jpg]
The blue housing pressed down over the stack, with the circuit board visible through the square window in its centre.
   

5. **Push the keyboard switch in.** Line the switch up so its two metal pins are
   straight, then press it down through the square window until it seats flat
   against the board. It will take a firm push and then stop.

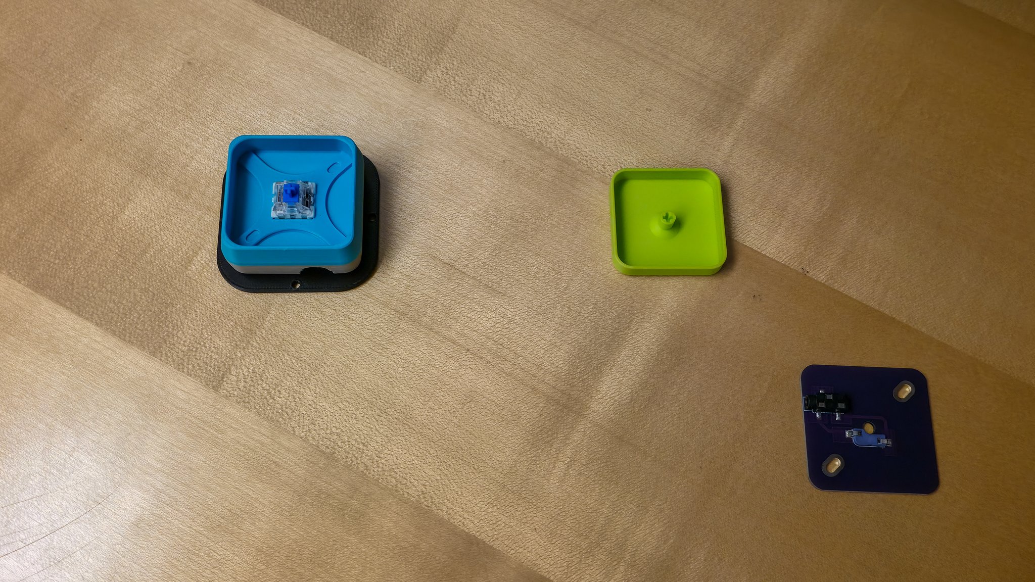
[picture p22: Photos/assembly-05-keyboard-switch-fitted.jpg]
The blue and clear mechanical keyboard switch pushed through the square window and seated flat against the board, its cross-shaped stem pointing up.
   

   If the pins are bent, straighten them with tweezers or small pliers before
   pushing, because a bent pin will fold over instead of entering the socket.

6. **Press the keycap on.** Push your chosen `Part_4.x` keycap onto the cross
   shaped stem on top of the keyboard switch. It only goes on one way, and it
   pushes on by hand. The Click Me is now finished.

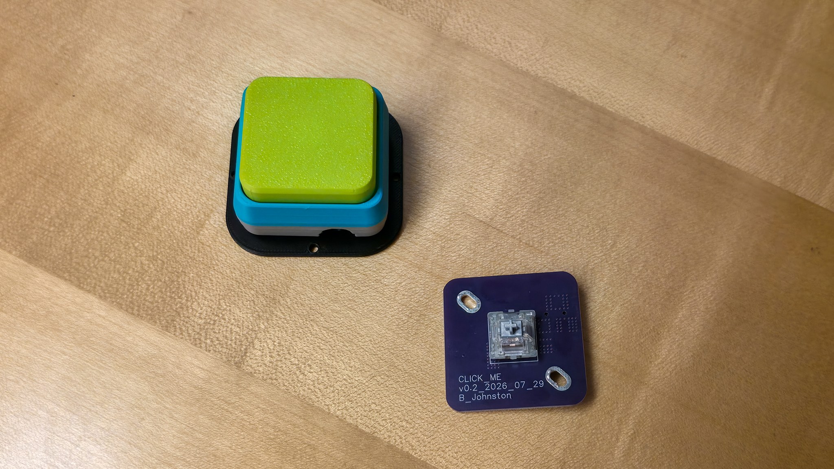
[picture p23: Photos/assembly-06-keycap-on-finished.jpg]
The finished Click Me: a textured lime-green keycap on the light blue housing and black base, beside a spare circuit board with a keyboard switch fitted in its centre.
   

## 6. Test it

1. Plug one end of a 3.5 mm mono cable into the notch in the side of the Click Me.
2. Plug the other end into the switch socket of the device you want to operate:
   a switch-adapted toy, a communication aid, or a switch interface.
3. Press the keycap. The device should respond for as long as you hold it down,
   and stop when you let go.

Below, a Click Me connected by cable to a switch-adapted toy fire truck, first with
the truck idle and then with the keycap pressed and the truck lit up and running.

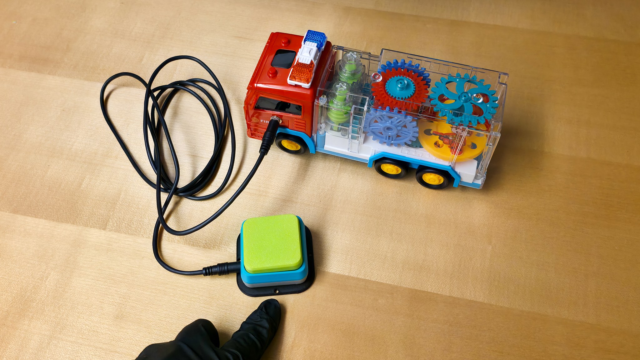
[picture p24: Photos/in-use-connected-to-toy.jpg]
The finished Click Me on a wood table, connected by a loosely coiled black cable to a toy fire truck with a red cab and a clear body of coloured gears. The truck is unlit and a gloved hand rests nearby.


A black-gloved finger presses the lime-green button and the fire truck lights up, with teal beams shining from its side across the table.

## 7. If something does not work

| What you see | What it usually means | What to do |
|---|---|---|
| Nothing happens when you press | The target device is off, or expects a different connector | Confirm the target device works with another switch first |
| Nothing happens, and another switch works | A keyboard switch pin missed the socket | Pull the keyboard switch out, check both pins are straight, push it back in |
| It works only sometimes, or stutters | The keyboard switch is not fully seated | Press it firmly until it stops moving |
| It triggers on its own | The keycap is fouling the housing window and holding the switch partly down | Check the keycap moves freely; reprint with a slightly smaller horizontal expansion if it rubs |
| The keycap will not push on | The stem opening printed undersize | Clear any stringing from the stem cavity, or reprint with more horizontal expansion |
| The housing springs back open | A snap feature did not print cleanly, or a wall is too thin | Check for stringing on the mating edges; reprint with three or more walls |
| The cable will not reach the jack | The board is in back to front | Take it apart and check the jack points at the notch in the base edge |

## 8. Help improve this design

This is a prototype and feedback is what moves it forward. Useful things to report:
whether the snap fit worked on your printer, which keyboard switch you chose and
how the force suited the person using it, and whether any step above was unclear.

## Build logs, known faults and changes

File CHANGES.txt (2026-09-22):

Click Me changelog
==================

v0.5.0 (2026-09-21)
  First published version. Work in progress.

  Hardware
    - Circuit board v0.2 (silkscreen dated 2026_07_29), 46 x 46 mm, 2 layers.
      PJ-320B 3.5 mm mono jack wired tip-and-sleeve through a Cherry MX
      compatible hot-swap socket. Ring deliberately unconnected.
    - Boards manufactured and assembled by JLCPCB, July 2026.
    - Printed housing v0.5: four parts (base, carrier, retainer, housing) plus
      five interchangeable keycaps. Snap-fit, no fasteners.

  Files
    - Gerbers re-exported from EasyEDA Pro v3.2.149 on 2026-09-21. Verified to
      produce the same board as the manufactured set: all drill coordinates and
      every aperture used for drawing are identical to the as-manufactured files.
      The only differences are aperture declarations that are never selected.
    - JLCPCB parts list and placement files list CN1 and U1 only. U2, the
      mechanical keyboard switch, is a footprint for housing alignment and is
      supplied by the maker.

  Cost, as built
    - 25 assembled boards, July 2026: $120.59 delivered, $4.82 per board.
      These are the boards in the photographs. The batch was kept small
      deliberately, to test a design correction before ordering more.
      The earlier revision ran to 50 boards at $118.10, or $2.36 per board.
    - One finished Click Me: $8.43, made up of board $4.82, cable $3.00,
      filament $0.42, mechanical keyboard switch $0.19.
    - Everything was bought in small volumes, so these are ceiling prices.
      Bulk pricing to be explored once the design is finalised.

  Assembly animation
    - Photos/assembly-animation.gif shows the parts coming together, rendered
      from Fusion 360. It plays once and stops rather than looping, so it does
      not become motion a reader cannot pause.
    - Full version on YouTube: https://youtu.be/RXbbdtwFPiI
    - Rendered from housing revision v0.32, not the v0.5 parts shipped here.

  Known limitations
    - CAD source files for the printed parts are not yet published. They exist
      in Fusion 360 and will be added after cleanup.
    - Print settings in ASSEMBLY.md are a suggested starting point, not a
      verified profile.
    - No recommended actuation force is stated yet.

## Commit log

2026-09-22 Click Me: Solderless Hot-Swap Access Switch
    A 3.5 mm assistive-technology access switch built around a small custom
    board: a PJ-320B jack wired tip and sleeve through a Cherry MX compatible
    hot-swap socket. JLCPCB solders both parts, so nobody building one solders
    anything. The mechanical keyboard switch pushes into the socket by hand,
    and swapping it changes the actuation force in seconds without tools.
    What is here: a fresh Gerber export verified against the manufactured
    board, the JLCPCB parts and placement files, nine STL parts for the
    snap-fit housing and five keycap options, step-by-step ordering and
    assembly guides with every photograph described in text, real costs from
    my own order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
    [BOM.csv, BOM_Board1_PCB1_2026-09-21.xlsx, BOM_ClickMe.csv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]
2026-09-22 Add a photo of three finished Click Me switches with different keycaps
    The photo shows three of the five keycaps printed and fitted, on housings
    printed in different colours: the flat Part_4.0, the tall flat-topped
    Part_4.3, and Part_4.4 with its tactile pattern. It sits in ASSEMBLY.md
    section 4 after the keycap rendering, and in the README after the list of
    features. Both places describe it in words.
2026-09-22 Replace a dash with a colon in the testing steps
    Step 2 of section 6 in ASSEMBLY.md used a hyphen as a dash before the list
    of devices. A colon does the same job.
